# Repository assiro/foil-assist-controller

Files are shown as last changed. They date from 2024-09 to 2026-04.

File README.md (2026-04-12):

# TecnoFly — Foil Assist Remote Controller

**A wireless remote control system for electric hydrofoil assist, built around ESP32 and ESP-NOW.**

> Main project website: [www.foilassistproject.com](http://www.foilassistproject.com)

---

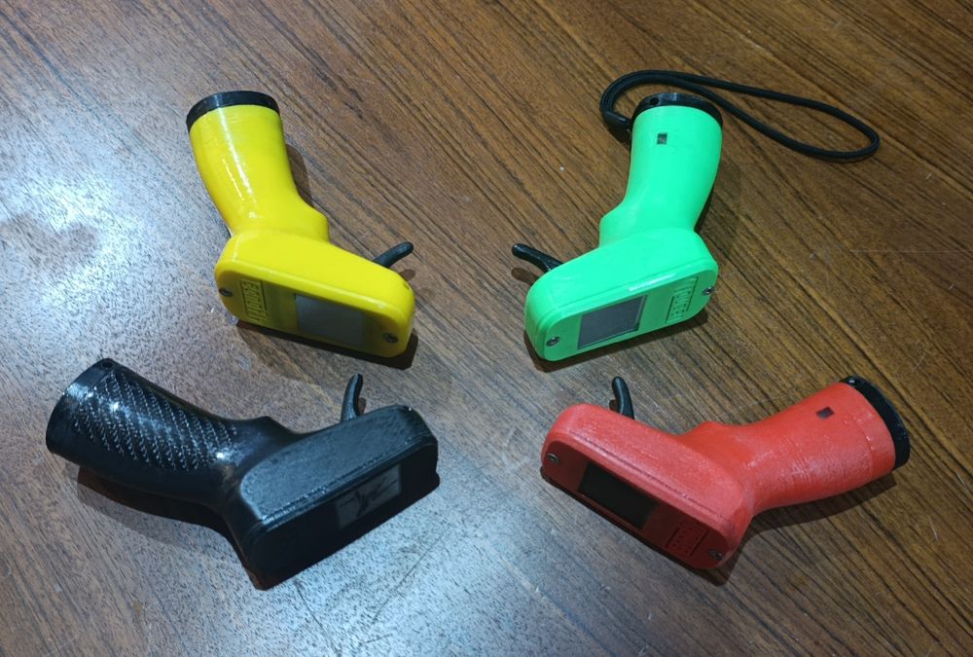
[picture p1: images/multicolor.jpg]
Controller variants

*3D-printed controller housings in multiple colors*

---

## Overview

This project provides a complete wireless remote control system designed specifically for electric hydrofoil (e-foil) motor assist. While it was born for hydrofoil use, it can also be used with electric skateboards, tow boggies, and other ESC-driven devices.

The system consists of two main components:

- **Transmitter** — a handheld pistol-grip controller with a Hall-effect throttle sensor and a 1.54" ePaper display
- **Receiver** — an ESP32 module mounted inside the board, connected to a VESC 75100 motor controller

Communication uses the **ESP-NOW** protocol, a peer-to-peer Wi-Fi protocol that allows direct, low-latency data exchange between ESP32 devices using their MAC addresses — no router or network infrastructure required.

---

## Hardware

### Transmitter

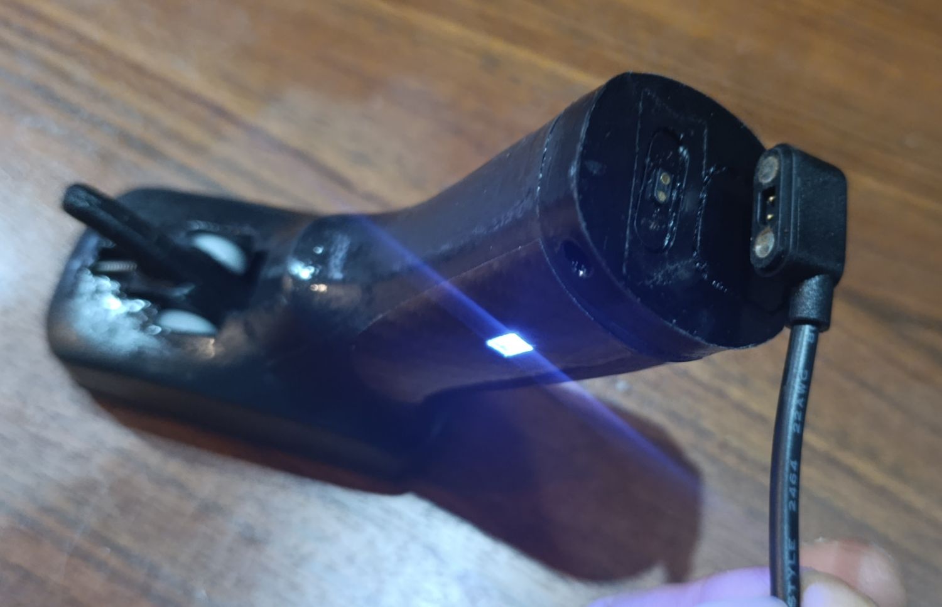
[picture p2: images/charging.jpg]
Controller charging

*Transmitter with magnetic charging connector and status LED*

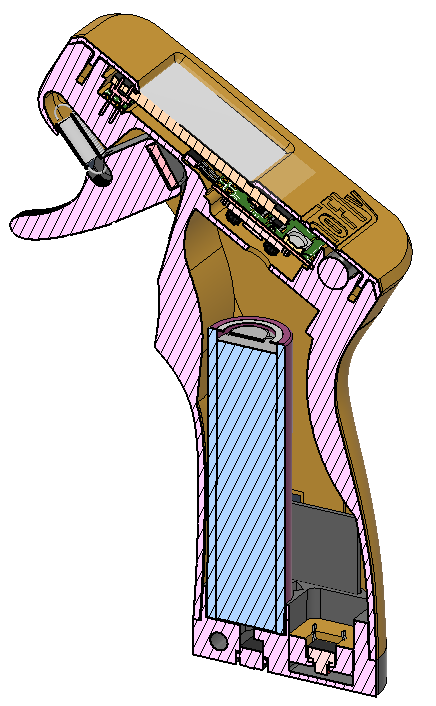
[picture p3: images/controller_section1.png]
Controller section view

*Internal cross-section: battery, PCB, ePaper display, and trigger mechanism*

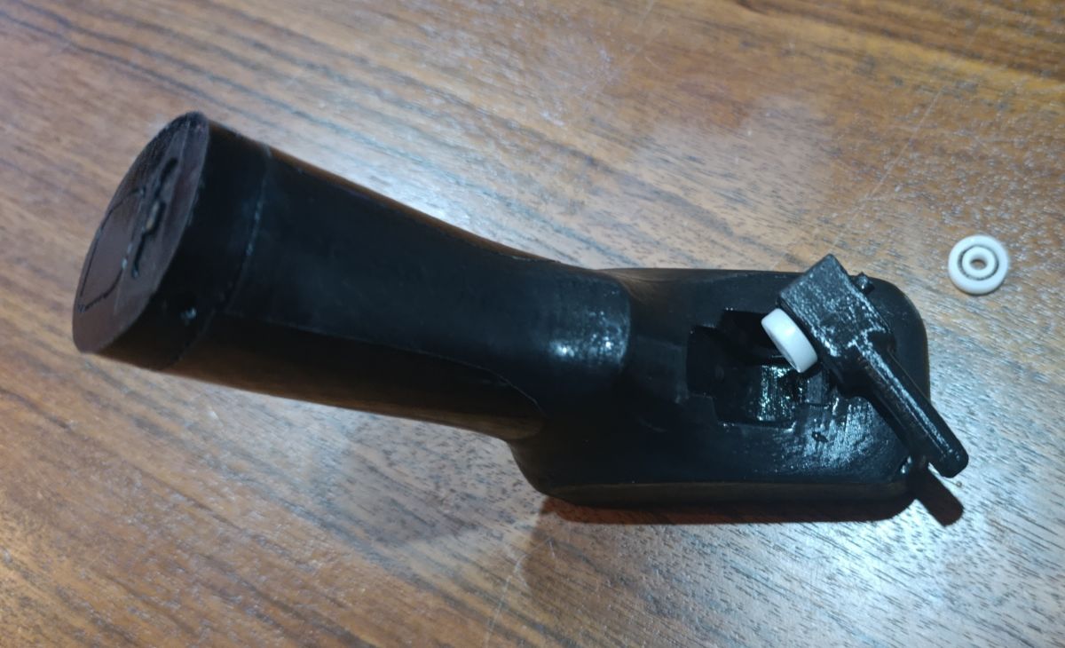
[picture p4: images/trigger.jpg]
Trigger mechanism

*Hall-effect throttle trigger assembly*

**Key components:**
- ESP32-C3 Zero microcontroller
- OH49E Hall-effect sensor (throttle)
- WeAct 1.54" ePaper display (200×200, SSD1681)
- 18650 Li-Ion battery (3.6V)
- Power bank circuit module (5V boost)
- Vibration motor (haptic feedback)
- Magnetic charging connector (pogo pins)
- AO3400 N-channel MOSFETs
- Custom PCB (TecnoFly PCB0425)
- STL 3D print parts: https://www.thingiverse.com/thing:6746363

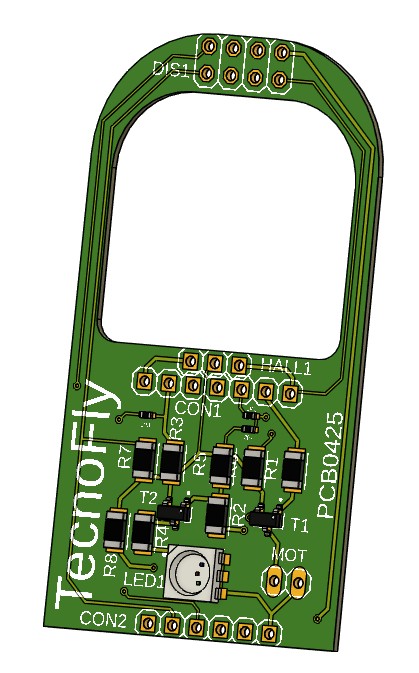
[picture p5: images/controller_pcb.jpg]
Controller PCB

*Custom PCB — TecnoFly PCB0425*

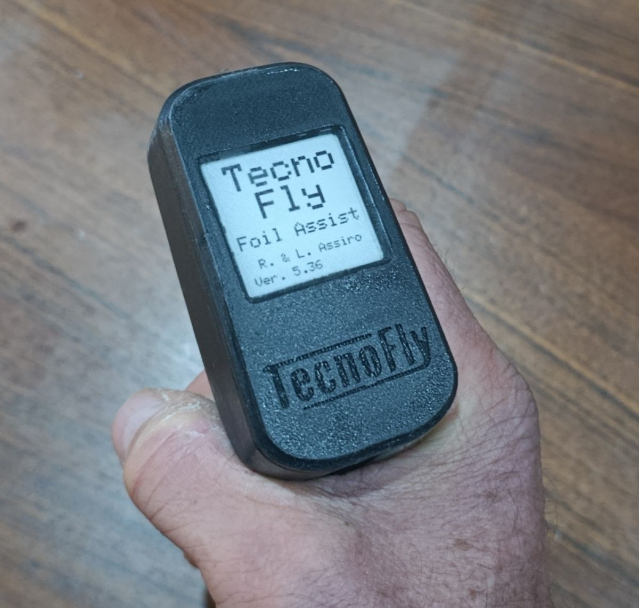
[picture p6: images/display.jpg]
ePaper display

*1.54" ePaper display showing startup screen with firmware version*

#### Transmitter Schematic

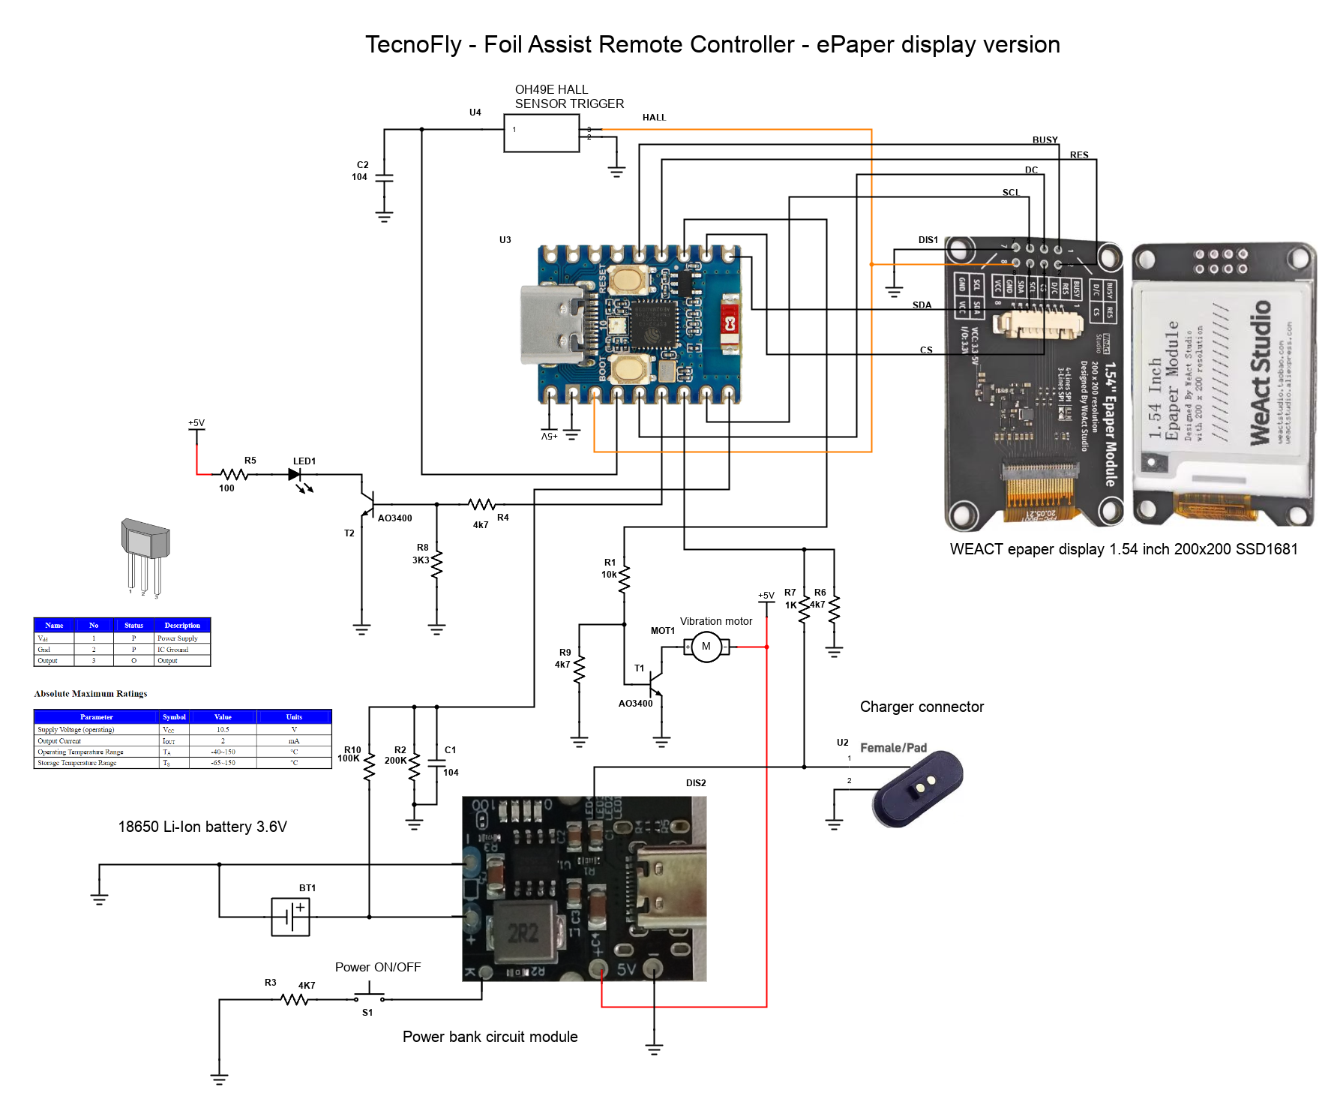
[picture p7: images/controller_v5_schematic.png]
Schematic

*Full schematic — TecnoFly Foil Assist Remote Controller (ePaper display version)*

---

### Receiver

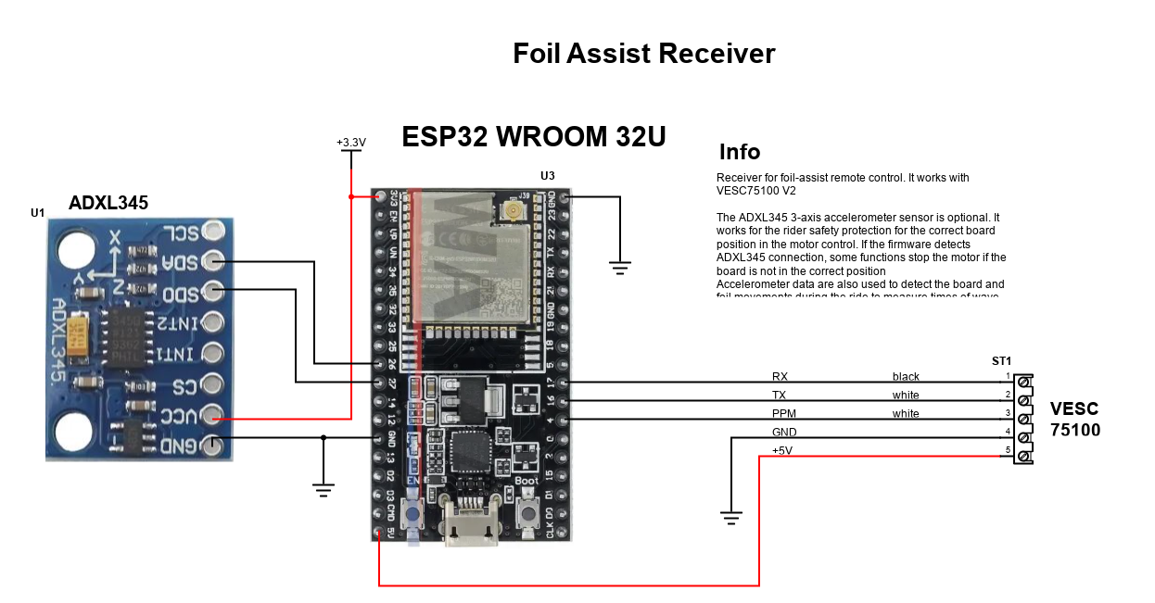
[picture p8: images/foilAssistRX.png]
Receiver schematic

*Receiver schematic — ESP32 WROOM 32U connected to VESC 75100*

**Key components:**
- ESP32 WROOM 32U module
- ADXL345 3-axis accelerometer *(optional but recommended)*
- VESC 75100 motor controller interface (UART + PPM)

The ADXL345 accelerometer is optional but provides important safety and analytics features:
- Stops the motor if the board is not in the correct riding position
- Detects board and foil movements to measure wave timing and pump cadence

---

## Radio Transmission

2.4 GHz radio is highly sensitive to water — it can be completely blocked when the remote is submerged. To address this, a **passive antenna is installed inside the board**, extending the effective range even when the rider's hand dips into the water.

---

## Data Logging & Analytics

A key design goal was full data ownership and ride analytics. The receiver logs the following data **every second** for each ride session:

- Battery voltage and state of charge
- Power consumption (W)
- Throttle level
- Motor power output
- Board physical position (from ADXL345)
- Board acceleration

Each ride generates a separate data file stored on the receiver. A **Wi-Fi hotspot** is created by the receiver, allowing the rider to connect via any browser and view graphical charts of the last 10 rides — no app required.

The firmware also provides real-time feedback on the remote display, including performance metrics for wave riding and pump foiling sessions.

---

## Firmware Features

- Wireless throttle control via ESP-NOW
- Real-time ePaper display (battery level, speed, motor power, ride mode)
- Vibration motor feedback
- Ride data logging to flash memory
- Wi-Fi web interface for ride data visualization
- Safety cutoff based on board orientation (when ADXL345 is connected)
- Multiple riding modes

---

## Repository Structure

```
foil-assist-controller/
├── transmitter/       # ESP32-C3 Zero firmware (handheld remote)
├── receiver/          # ESP32 WROOM 32U firmware (board-mounted)
├── images/            # Photos and schematics
└── README.md
```

---

## Getting Started

1. **Hardware:** Assemble the transmitter and receiver circuits according to the schematics above.
2. **Pair devices:** Flash both firmwares and update the MAC address of the receiver in the transmitter firmware.
3. **VESC configuration:** Connect the receiver to the VESC 75100 via UART (RX/TX) and PPM.
4. **Power on:** The transmitter display will show the startup screen and firmware version on boot.
5. **Ride data:** After a session, connect to the receiver's Wi-Fi hotspot and open a browser to view ride analytics.

---

## Credits

Designed and developed by **R. & L. Assiro** — TecnoFly  
Firmware version: 5.36

---

## License

This project is open source. See [LICENSE](LICENSE) for details.

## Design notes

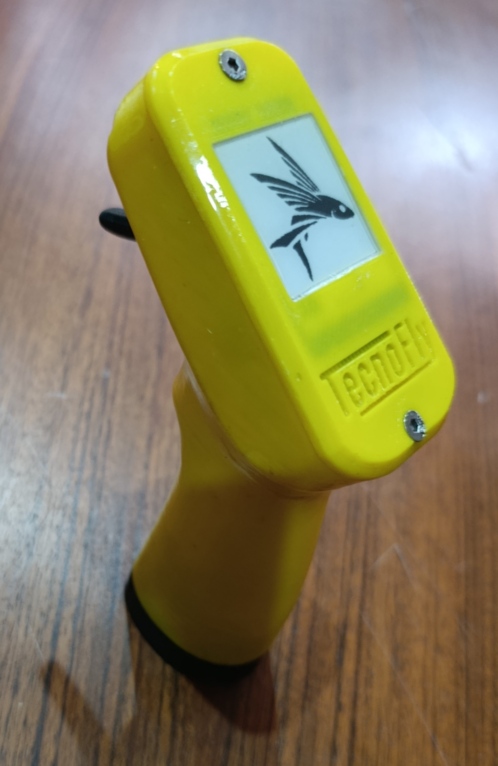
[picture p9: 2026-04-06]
transmitter/controller image/remote1.jpg

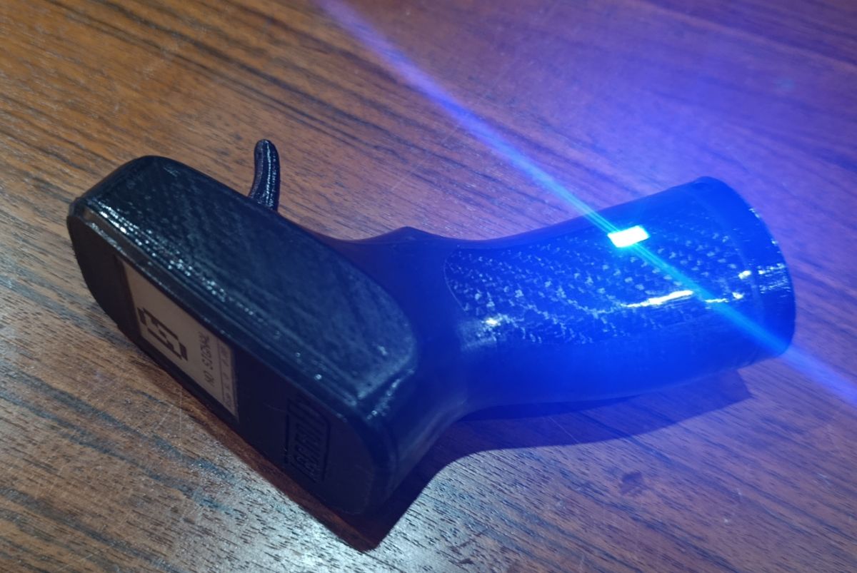
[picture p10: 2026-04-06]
transmitter/controller image/controller1.jpg

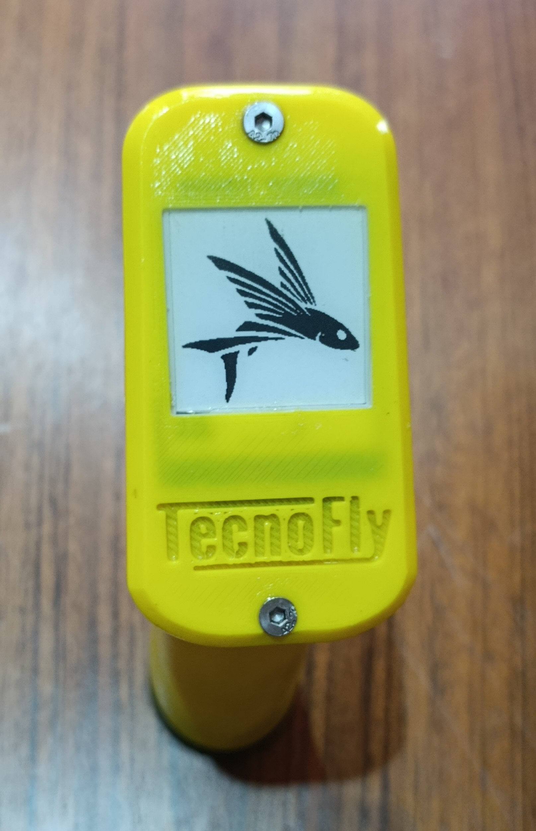
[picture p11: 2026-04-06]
transmitter/controller image/remote2.jpg

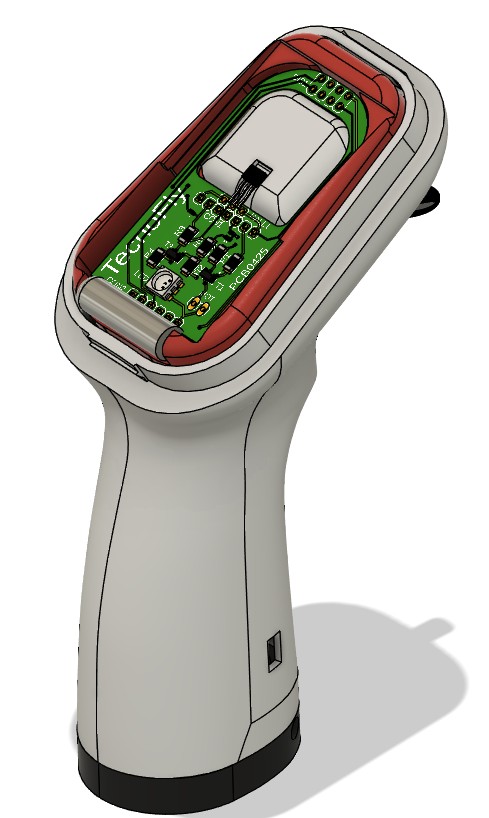
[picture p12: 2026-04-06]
transmitter/controller image/case_open.jpg

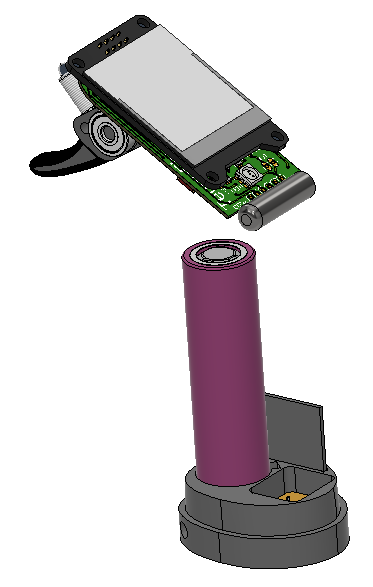
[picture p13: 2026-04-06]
transmitter/controller image/internal1.png

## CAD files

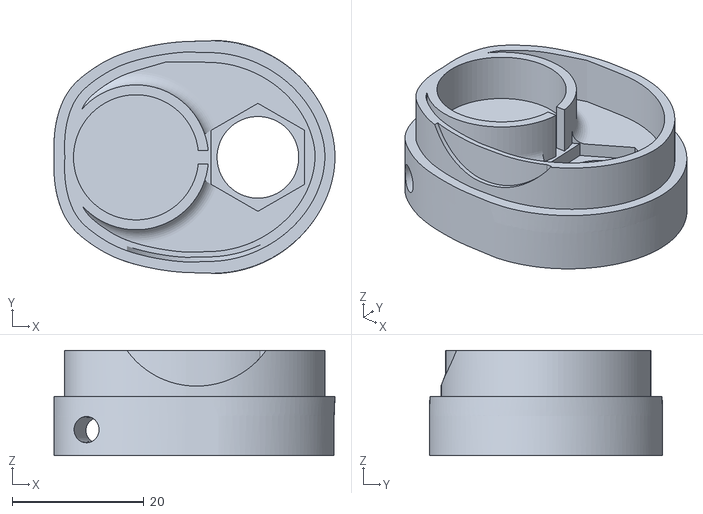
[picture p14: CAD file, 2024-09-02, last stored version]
transmitter/stl/controller body bottom.stl
42.7 x 35.4 x 16.0

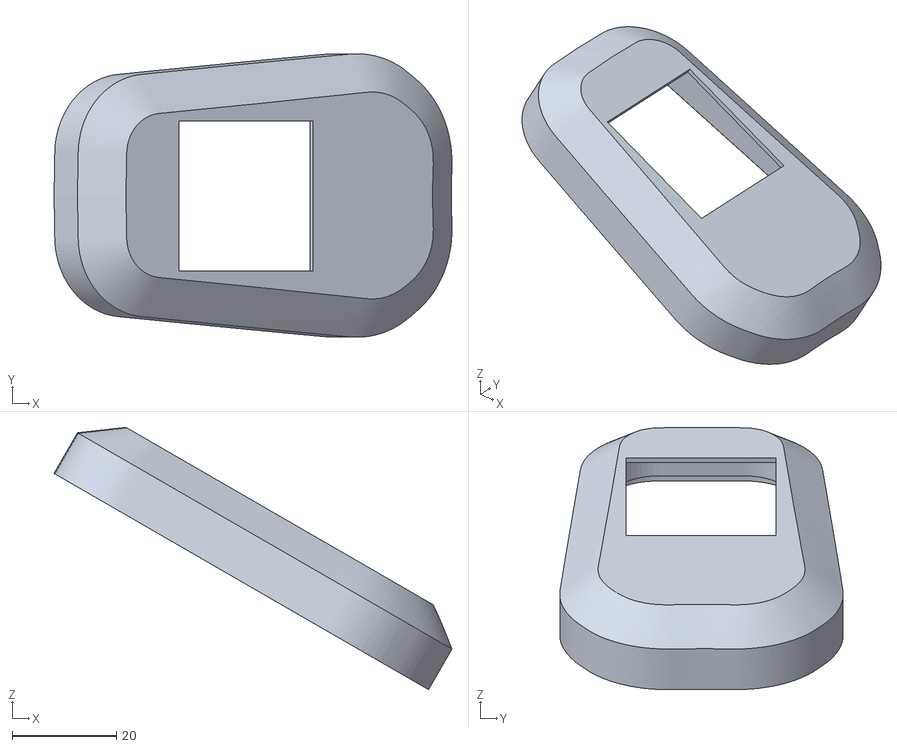
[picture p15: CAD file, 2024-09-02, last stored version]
transmitter/stl/controller body top.stl
76.4 x 54.4 x 50.3

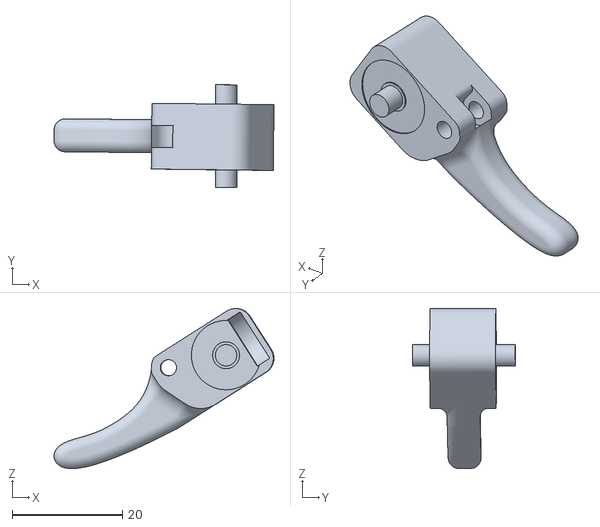
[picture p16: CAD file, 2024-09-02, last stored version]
transmitter/stl/trigger.stl
40.0 x 18.7 x 29.1

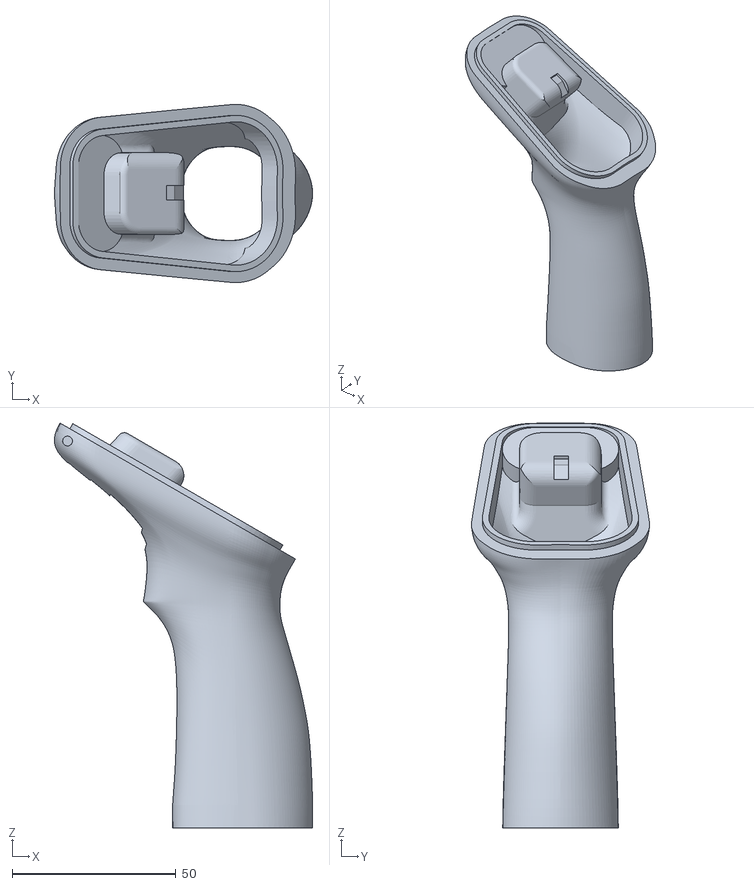
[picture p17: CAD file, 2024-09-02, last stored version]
transmitter/stl/controller body.stl
78.8 x 54.4 x 123.6

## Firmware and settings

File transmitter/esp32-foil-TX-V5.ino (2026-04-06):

/*
    TecnoFly remote controller for Foil Assist system
    2025 writed by Roberto Assiro
    
    This program is free software under the terms of the GNU General Public License 
    as published by the Free Software Foundation.
    VERSION 5.xx jan 2025 - EPAPER DISPLAY version GDEH0154D67 200x200, SSD1681
    ESP32 Core 3.5.5 + FreeRTOS
*/
#include <WiFi.h>
#include <esp_wifi.h>
#include <esp_now.h>
#include <FS.h>
#include <SPI.h>
#include <Wire.h>
#include <Adafruit_GFX.h>
#include <U8g2lib.h>
#include <EEPROM.h>
#include <DNSServer.h>
#include <WiFiUdp.h>
#include <ArduinoOTA.h>
#include <ESP32httpUpdate.h>
#include <Update.h>
#include <AsyncTCP.h>
#include <HTTPClient.h>
#include "image.h"
#define ENABLE_GxEPD2_GFX 1
#include <GxEPD2_BW.h>
#include <GxEPD2_3C.h>
#include <Adafruit_NeoPixel.h>

#include <freertos/FreeRTOS.h>
#include <freertos/task.h>
#include <freertos/semphr.h>

# define LED  2
# define CHARGING 3
# define VIBRATOR  8
# define hallPin  0

#define WS_LED_PIN 10            // patch to turn off led ws2812 on esp32 c3 zero
#define WS_LED_COUNT 1
Adafruit_NeoPixel wsLED(WS_LED_COUNT, WS_LED_PIN, NEO_GRB + NEO_KHZ800);

// 1.54'' EPD Module
GxEPD2_BW<GxEPD2_154_D67, GxEPD2_154_D67::HEIGHT> 
display(GxEPD2_154_D67(/*CS=*/ 7, /*DC=*/ 1, /*RES=*/ 9, /*BUSY=*/ 10)); // GDEH0154D67 200x200, SSD1681

String VERSION = "5.36";
const char* ssidService     = "tecnofly";
const char* passwordService = "tecnofly";

String upgradeServer = "http://www.eoloonline.it/firmware/foilAssist/";
String upgradeFile = "foilAssistController5.bin"; 
#define EEPROM_SIZE 16
bool espState = false;   
bool firstConnection = false;

uint8_t THmode = 0; // Throttle mode
uint displayMode; // display view mode
bool espStatus = false;

unsigned long lastTime;  
const unsigned long transmissionInterval = 100;  // send throttle to receiver in ms
const unsigned long displayUpdateInterval = 800; // update epaper display every xxx ms
unsigned long vibrationTimeOff;
unsigned long vibrationTime = 0; 
unsigned long timerOff = 0; 
unsigned long timerNoConnect = 0; 
int hallValue;
int throttle;
int triggerValue;
int counter;
bool lowBatt = false;
bool lock = true;
uint valMin = 1600;
uint valMax = 2600;
uint valMiddle = ((valMax - valMin) / 2) + valMin;
//uint waveBuffer[10];
//uint takeOffBuffer[10];
//uint waveBestTimeBuffer[10];
int partialCount = 0;
uint8_t maxPower;  // max power to send by throttle TEST
uint8_t TxPower;
uint8_t surfingSeconds;  // timer for seconds in surfing mode (throttle off)
uint16_t surfingMinutes;

// data from vesc
struct vescValues {
        float voltage;  
        float tempMosfet;
        float current;
        int power;
};

struct vescValues data;

long rpm;
float inpVoltage;  
float tempMosfet;
float avgInputCurrent;
float watt;
int batpercentage;
int file;
uint powerCounter;
uint powerAverage;
uint powerIndex;
float receiverVersion;
char message1[9];
char message2[9];
char message3[9];  
int Tminutes;
int Tseconds;
int Mminutes;
int Mseconds;  
uint takeOff;
uint wave;
uint waveBestTime;
uint rideNumber;
bool gravityAlarm;
bool riderAlert;
bool vibrationAlarm = false;
bool justOneAlert;

uint boardCode;
uint8_t broadcastAddress[6] = {0x4C, 0x11, 0xAE, 0x0D, 0xE5, 0x35};//RECEIVER MAC ADDRESS
esp_now_peer_info_t peerInfo;

// Must match the receiver structure// Structure example to send data
typedef struct struct_message {
        float a;
        float tempMosfet;  
        float avgInputCurrent;  
        int watt;
        int batt;
        int file;
        uint powerCounter;
        uint powerAverage;
        uint powerIndex;
        float receiverVersion;
        char message1[9];
        char message2[9];
        char message3[9];  
        int Tminutes;
        int Tseconds;   
        int Mminutes;
        int Mseconds;  
        uint takeOff;
        uint wave;
        uint waveBestTime;
        uint rideNumber;
        bool gravityAlarm;
        bool riderAlert = false;
        //float watthour;
} struct_message;

struct myData {int a;};

// Create a struct_message called myData
struct_message myData;
struct_message incomingReadings;

// ================== MUTEX & DATA ==================
SemaphoreHandle_t dataMutex;
struct TxData {
    uint16_t trigger;
    uint8_t status;
    uint32_t counter;
};

TxData txData;

// Callback when data is sent
void OnDataSent(const esp_now_send_info_t *info, esp_now_send_status_t status) {  
  if (status == 0){
        espStatus = true;
  }else{
//    Serial.println("ESP_NOW delivery fail...");
        espStatus = false;
  }
}

void OnDataRecv(const esp_now_recv_info_t *info, const uint8_t *incomingData, int len){    
      memcpy(&incomingReadings, incomingData, sizeof(incomingReadings));
      inpVoltage = incomingReadings.a;
      tempMosfet = incomingReadings.tempMosfet;
      avgInputCurrent = incomingReadings.avgInputCurrent;
      watt = incomingReadings.watt;
      batpercentage = incomingReadings.batt;
      file = incomingReadings.file+1;    
      powerCounter = incomingReadings.powerCounter;
      powerAverage = incomingReadings.powerAverage;
      powerIndex = incomingReadings.powerIndex;
      receiverVersion = incomingReadings.receiverVersion;
      Tminutes = incomingReadings.Tminutes;
      Tseconds = incomingReadings.Tseconds;      
      Mminutes = incomingReadings.Mminutes;
      Mseconds = incomingReadings.Mseconds;    
      wave = incomingReadings.wave;
      takeOff = incomingReadings.takeOff;
      waveBestTime = incomingReadings.waveBestTime;    
      gravityAlarm = incomingReadings.gravityAlarm;  
      riderAlert = incomingReadings.riderAlert;      
//      waveBuffer[incomingReadings.rideNumber] = incomingReadings.wave;
//      takeOffBuffer[incomingReadings.rideNumber] = incomingReadings.takeOff;
//      waveBestTimeBuffer[incomingReadings.rideNumber] = incomingReadings.waveBestTime; 

      firstConnection = true;
  //    if(incomingReadings.rideNumber != 0){Serial.println(incomingReadings.rideNumber);}
  //    Serial.println(receiverVersion);           
 //Serial.println(riderAlert);    
}


////  MODIFICA 
// ================== PROTOTYPES ==================
void espnowTask(void *pvParameters);
void logicTask(void *pvParameters);
void displayTask(void *pvParameters);


void setup() {
    Serial.begin(115200); 
    WiFi.mode(WIFI_STA);    

    pinMode(WS_LED_PIN, INPUT);
    wsLED.begin();      // Abilita il controllo WS2812
    wsLED.clear();      // Imposta 0,0,0
    wsLED.show();       // ⚡ Spegne il LED in <1ms
      

    pinMode(LED, OUTPUT);
    pinMode(VIBRATOR, OUTPUT);
    pinMode(CHARGING, INPUT);
    digitalWrite(LED , 0);
    digitalWrite(VIBRATOR , 0);
    analogReadResolution(12);
    EEPROM.begin(32);


delay (200);    
TxPower = EEPROM.read(9);
if(TxPower > 5){TxPower = 5;}
Serial.print("Tx Power: "); Serial.println(TxPower);

switch (TxPower) {
        case 0: WiFi.setTxPower(WIFI_POWER_2dBm); break;
        case 1: WiFi.setTxPower(WIFI_POWER_5dBm); break;
        case 2: WiFi.setTxPower(WIFI_POWER_7dBm);break;
        case 3: WiFi.setTxPower(WIFI_POWER_8_5dBm);break;
        case 4: WiFi.setTxPower(WIFI_POWER_11dBm); break;
        case 5: WiFi.setTxPower(WIFI_POWER_15dBm); break;
}
//    WiFi.setTxPower(WIFI_POWER_15dBm); // best work for esp32 c3 super mini and zero

//    esp_wifi_set_max_tx_power(80); // ≈ +21 dBm valori: 8 → 84 (unità = 0.25 dBm)
//    esp_wifi_set_channel(1, WIFI_SECOND_CHAN_NONE);  // fixed channel (es. 1)
//    esp_wifi_set_protocol(WIFI_IF_STA, WIFI_PROTOCOL_LR);  // enable long range

    display.init(); 
    macSetting();  
    // Init ESP-NOW
    if (esp_now_init() != 0) {
        Serial.println("Error initializing ESP-NOW");
        return;
    }else{
        Serial.println("ESP-NOW initializing OK!");
    }

    esp_now_register_send_cb(OnDataSent);
    esp_now_register_recv_cb(OnDataRecv);

    // Register peer
    memcpy(peerInfo.peer_addr, broadcastAddress, 6);
    peerInfo.channel = 0;  
    peerInfo.encrypt = false;
    
    // Add peer        
    if (esp_now_add_peer(&peerInfo) != ESP_OK){
        Serial.println("Failed to add peer");
        return;
    }

    // ---------- MUTEX ----------
    dataMutex = xSemaphoreCreateMutex();

    startingEpaperDisplay();
    firstInit();
    //hallTest();  // ONLY FOR TEST WITH USB CONNECTED 

     // ---------- TASKS ----------
    xTaskCreate(espnowTask, "ESPNow", 4096, NULL, 3, NULL);
    xTaskCreate(logicTask, "Logic", 4096, NULL, 2, NULL);
    xTaskCreate(displayTask, "Display", 8192, NULL,1, NULL);

}


void loop() {vTaskDelay(portMAX_DELAY);}


// ================== TASK ESP-NOW ==================
void espnowTask(void *pvParameters) {
    TickType_t lastWake = xTaskGetTickCount();
    for (;;) {
            if (xSemaphoreTake(dataMutex, portMAX_DELAY)) {
                xSemaphoreGive(dataMutex);
            }
            read_throttle();
            if (throttle > 10) {
                        timerOff = 0;
                        timerNoConnect = 0;
                        if(lock){unlock();}
            } else {
                        timerOff++;
                        surfingSeconds = (timerOff / 10) / 60;
                        surfingMinutes = (timerOff / 10) % 60;
            }
            switch (THmode) {
                case 1: throttle = strong_throttle_curve(throttle); break;
                case 2: throttle = mid_throttle_curve(throttle); break;
                case 3: throttle = soft_throttle_curve(throttle); break;
                case 4: throttle = angular_throttle_curve(throttle); break;
                case 5: throttle = eco_throttle_curve(throttle); break;
            }
            esp_now_send(broadcastAddress, (uint8_t *)&throttle, sizeof(throttle));
            vTaskDelayUntil(&lastWake, pdMS_TO_TICKS(transmissionInterval));
        }
}

// ================== TASK LOGIC ==================
void logicTask(void *pvParameters) {
    for (;;) {
        if (xSemaphoreTake(dataMutex, portMAX_DELAY)) {
                if(lowBatt){
                    digitalWrite(LED , 1);
                }else{
                    digitalWrite(LED , 0);
                }
                if(gravityAlarm){
                        if(!lock){
                            throttle = 0;
                            lock = 1;                    
                            vibration_confirm(800);
                        }
                }

                if((riderAlert) and (displayMode == 3)){vibrationTime = 1500;}   //new time record on surfing or pump by vibration alert

                vibration();
                checkCharging();

                txData.status = 1;
                txData.counter++;
                xSemaphoreGive(dataMutex);
        }
        vTaskDelay(pdMS_TO_TICKS(20));
    }
}


///////////////////////////////
//######## FUNCTIONS #########

void startingEpaperDisplay(){  
        display.setRotation(0);
        display.setFont(NULL); 
        display.setTextColor(GxEPD_BLACK);
        display.fillScreen(GxEPD_WHITE);     
        delay(500);
        display.setFullWindow();
//        display.setPartialWindow(0, 0, 200, 200); 
        display.nextPage();
        delay(2000);
        checkCharging();
        display.setPartialWindow(0, 0, 200, 200);
        display.firstPage();
        display.setTextSize(6); 
        display.setCursor(15, 5); 
        display.print("Tecno"); 
        display.setCursor(50, 55); 
        display.print("Fly"); 
        display.setTextSize(3);      
        display.setCursor(0,115);
        display.println("Foil Assist");
        display.setTextSize(2);
        display.setCursor(20,155);
        display.println("R. & L. Assiro");
        display.setCursor(5,180);
        display.print("Ver. ");
        display.print(VERSION);
        display.nextPage();
        delay(3000);
        digitalWrite(LED,1);
        displayBitmap(0, 0, TecnoFlyLogo, 200, 200);
        delay(2000);  
        digitalWrite(LED,0);

}


void vibration(){
          int timeOn = vibrationTime;
          if ((vibrationTimeOff + vibrationTime + timeOn < millis()) and (vibrationTime > 0)) {
                digitalWrite(VIBRATOR,1);
                vibrationTimeOff = millis();
          }else if(vibrationTimeOff + vibrationTime < millis()) {
                digitalWrite(VIBRATOR,0);
                vibrationTime = 0;
          }      
}


void vibration_confirm(int vibrationTime){
      digitalWrite(LED,1);
      digitalWrite(VIBRATOR,1);
      delay(vibrationTime);          
      digitalWrite(LED,0);
      digitalWrite(VIBRATOR,0);
}



void macSetting(){
        uint8_t currentMAC[6];
        WiFi.macAddress(currentMAC);
        Serial.println("");
        Serial.print("MAC originale: ");
        for (int i = 0; i < 6; i++) {
                if (i > 0) Serial.print(":");
                Serial.printf("%02X", currentMAC[i]);
        }
        Serial.println();     
        uint8_t lsb = EEPROM.read(13);
        uint8_t msb = EEPROM.read(14);
        broadcastAddress[4] = msb;  // aggiorna il terzo byte
        broadcastAddress[5] = lsb;  // aggiorna il quarto byte
        boardCode = (msb << 8) | lsb;
        Serial.print("EEPROM serial number: ");
        Serial.println(boardCode);  

        Serial.print("BROADCAST MAC ADDRESS: ");
        for (int i = 0; i < 6; i++) {
                if (i > 0) Serial.print(":");
                Serial.printf("%02X", broadcastAddress[i]);
        }
        Serial.println();
        uint8_t customMAC[6] = {0xA4, 0xCF, 0x12, 0xDC, msb, lsb};//TRANSMITTER MAC ADDRESS
        esp_err_t result = esp_wifi_set_mac(WIFI_IF_STA, customMAC);
        
        if (result == ESP_OK) {
            Serial.println("MAC address cambiato con successo!");
            Serial.print("NEW MAC:  ");
            Serial.println(WiFi.macAddress());                
        } else {
            Serial.print("Errore nel cambiare il MAC address. Codice errore: ");
            Serial.println(result);
        }
}


void checkCharging(){
      if (digitalRead(CHARGING) == HIGH) {
          do {
              displayBitmap(0, 0, chargerLogo, 200, 200); 
          } while (display.nextPage()); 
          delay(1000);                   
          display.hibernate();             
          esp_deep_sleep_start();       
      }
}

void unlock(){       
      bool exit = true;
      while(exit){
          digitalWrite(LED,0);  
          read_throttle();
          if(throttle < 10) {exit = false;}
          delay(500);
          digitalWrite(LED,1);
      }
      lock = false;
      throttle = 0;
      vibrationTime = 800;  // alert vibration before unlock
      delay(1000);
      vibrationTime = 600;
}

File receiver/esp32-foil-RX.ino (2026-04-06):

/*
    TecnoFly receiver for Foil Assist system
    2025 writed by Roberto Assiro
    
    This program is free software under the terms of the GNU General Public License 
    as published by the Free Software Foundation.
    VERSION 1.6x May 2025
    ESP32 FOIL ASSIST RECEIVER AND VESC DATA LOGGER
    Connections VESC: GPIO 16= white, 17= black, PPM white = GPIO 4
    Connections to SD CARD CS = GPIO 5
    // EEPROM byte usage: 0-3 = gravity check; 4-7 = service flag to upgrade; 8-11 = VESC offset; 12-15 life counter
    -REBOOT ISSUE .Downgrading to the previous version of esp32 Library board by espressif to version 3.0.7 solved the problem.
    -Library modify: ElegantOTA flag to enable AsyncWebServer mode file ElegantOTA.h
    VERSION 1.60 last firmware with LoRa module management
    -1.65 new pairing system and activated gravity sensor
    -2.00 NO SDCARD EXTERNAL - REPLACED WITH LITTLE FS on - all webserver file in flash - graph by uPlot
    -3.00 ADXL345 implement sensor 3 axis accelerometer and ESP core 3.3.6
*/
#include <WiFi.h>
#include <esp_now.h>
#include <AsyncTCP.h>
#include <FS.h>
#include <VescUart.h>
#include <ESP32Servo.h>
#include <esp_wifi.h>
#include <ESPAsyncWebServer.h>
#include <ESPmDNS.h>
#include <WiFiUdp.h>
#include <ArduinoOTA.h>
#include <HTTPClient.h>
#include <ESP32httpUpdate.h>
#include <EEPROM.h>
#include <DNSServer.h>
#include <ArduinoJson.h>
#include <ElegantOTA.h> // modificated of elegantOTA.h to enable AsyncWebServer mode
#include <Arduino.h>
#include <LittleFS.h>

#include <Wire.h>
#include <Adafruit_Sensor.h>
#include <Adafruit_ADXL345_U.h>

#define EEPROM_SIZE 32
#define escpin 4

const char* ssidService     = "tecnofly";
const char* passwordService = "tecnofly";

String upgradeServer = "http://www.eoloonline.it/firmware/foilAssist/";
String upgradeFile = "foilAssistReceiver.bin";
const char ssidName[] = "TecnoFly ";
char ssid[20];

const char* password = "";
String VERSION = "3.10";
const char* PARAM_INPUT_1 = "number";
const int GRAVITY1 = 33; // gravity sensor 1 for auto lock
const int GRAVITY2 = 32; // gravity sensor 2 for auto lock
Adafruit_ADXL345_Unified accel = Adafruit_ADXL345_Unified(12345);
IPAddress local_IP(192,168,10,1);//Set the IP address of ESP32 itself
IPAddress gateway(192,168,10,1);   //Set the gateway of ESP32 itself
IPAddress subnet(255,255,255,0);  //Set the subnet mask for ESP32 itself
DNSServer dnsServer;
AsyncWebServer server(80);
unsigned long ota_progress_millis = 0;
#define FORMAT_LITTLEFS_IF_FAILED true
VescUart UART;/** Initiate VescUart class */
File file;
int Poles = 14;                  //Poles of motor
// battery 10s
int batEmptyValue = 320;    // value x 10
int batFullValue = 410;  // max voltage x 10
int minvoltage = 32;

// battery 12s
int batEmptyValue12s = 384;    // value x 10
int batFullValue12s = 492;  // max voltage x 10
int minvoltage12s = 38;

uint battFullCapacity = 400;//*(42-minvoltage)/(42-32); //Wh - for Molicel P42A 21700 - 10s3p

// accelerometer
float axOffset = 0;
float ayOffset = 0;
float azOffset = 0;
bool accelerometerConnected = false;
bool gravityAlarm;
bool checkPositionEnable = false;
uint thresholdDegrees;
unsigned long gravityStartThreshold = 3000; // ms time to lock due tilt over
unsigned long gravityPositionStartTime = 0;
unsigned long gravityReleaseThreshold = 2000; // unlock time from tilt over
unsigned long gravityPositionReleseTime = 0;
bool switchPressed = false;
unsigned long switchPressStartTime = 0;
unsigned long switchReleaseStartTime = 0;

// VESC
struct VESCData {
        char time[6];   // mm:ss format
        int rpm;
        float voltage;
        float current;
        int watts;
        int throttle;
};

struct vescValues {
        float voltage;  
        float tempMosfet;
        float current;
        int power;
        int batt;
        int file;
        uint powerCounter;
        uint powerAverage;
        int powerIndex;
        float receiverVersion;
        char message1[9];
        char message2[9];
        char message3[9];  
        int Tminutes;
        int Tseconds;  
        int Mminutes;
        int Mseconds;    
        uint takeOff;
        uint wave;
        uint waveBestTime;
        uint rideNumber;
        bool gravityAlarm;
        bool riderAlert;
//        float watthour;
};
struct vescValues data;

bool espStatus = true;
bool vescReady = false;
float tempMosfet;
float rpm;
float voltage;
float current;
float motorCurrent;
int power;
float watthour;
int batpercentage;
uint batCapacity;
uint percentageOfCapacity;
unsigned long totalWatt;
uint powerCounter;
uint powerAverage;
int powerIndex;
uint voltageReadCounter;
float voltageAverage;
int fileName;
int Tminutes;
int Tseconds;
int Mminutes;
int Mseconds;
float receiverVersion;
float minVoltage = 50;
float maxTemp;
float maxCurrent;
int maxPower;
float voltageOffset;
char message1[9];
char message2[9];
char message3[9];
uint takeOff;
uint wave;
uint waveBestTime;
uint rideNumber;
bool riderAlert = false;
uint waveBestTimeOfTheRide;

Servo esc; 

//variables
int timeoutMax = 1500; //delay to stop motor without signal of trigger
int minPulseRate = 900; 
int maxPulseRate = 2150;
int throttle = 0;
bool receivedData = false;
uint32_t lastTimeReceived = 0;
uint32_t EspLastTimeReceived = 0;
uint32_t delays = 0;
uint32_t EspDelays = 0;
int rowCounter = 0;
int totalTime = 0;
char fileNameChar[1];
unsigned long lastDataVesc;
char dataFileName[20];
char jsonFileName[20];
bool recordEnable = false;
uint inactivityCounter;
bool serviceMode = false;
bool firstConnection = false;
bool oneTimeFlag = false;
uint timeNoRecord = 180; //max time in seconds to record data without trigger activity
uint lastAnalysis = 5; //minutes of total time after to do the data analysis every minute

volatile bool pendingServiceFlag = false;

// ---- RF signal quality ----
volatile int8_t  rssiLast    = 0;    
volatile int32_t rssiSum     = 0;    
volatile uint32_t packetCount = 0;   
volatile uint32_t packetLost  = 0;   
volatile float   rssiAvg     = 0.0f; 
uint32_t lastPacketTime      = 0;    
float lossPercent;

uint16_t boardCode; 
uint8_t broadcastAddress[6] = {0xA4, 0xCF, 0x12, 0xDC, 0xB5, 0x8E};//TRANSMITTER MAC ADDRESS STANDARD

esp_now_peer_info_t peerInfo;

// callback when data is sent
void OnDataSent(const esp_now_send_info_t *info, esp_now_send_status_t status) {       
    if (status == 1){
        espStatus = true;
    }else{
        espStatus = false;
    }
}
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

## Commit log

2024-09-02 stl remote parts
    [controller body bottom.stl, controller body top.stl, controller body.stl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]
2026-11-05 Add VESC Motor Controller compatibility section
    Added section about VESC motor controller compatibility and related details.
2026-11-05 Fix image filename for VESC controllers
    Updated image reference for VESC controllers in README.
2026-11-05 Fix typo in VESC motor controller description
